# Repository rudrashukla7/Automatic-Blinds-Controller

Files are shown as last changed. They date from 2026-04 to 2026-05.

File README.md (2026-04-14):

# Automatic-Blinds-Controller

A WiFi-enabled automated blinds system using an **ESP32**, **DRV8825 stepper driver**, and a **NEMA 17 stepper motor**.  
The system hosts a built-in web interface that allows real-time control of blinds from any device on the same network.

---

## Features

- Web-based control (no app required)
- Clean, responsive UI hosted directly on ESP32
- Smooth motion using 1/16 microstepping
- Manual open / close controls
- Timed movement (5-second presets)
- Instant stop functionality
- Dual-core multitasking (motor control runs independently)
- Quiet and precise operation

---

## Components Used

- ESP32 Development Board (30-pin NodeMCU)
- NEMA 17 Stepper Motor (12V, 1.5A)
- DRV8825 Stepper Motor Driver
- 12V battery or power supply
- Buck converter (5V for ESP32)
- 220µF capacitor (≥35V recommended)
- Jumper wires
- 3D printed gear (for #10 bead chain)
- Latch switch

---

## Wiring Diagram

- **Battery +** → DRV8825 VMOT → Buck Converter IN+  
- **Battery −** → DRV8825 GND → Buck IN− → Buck OUT− → ESP32 GND  

- **Buck OUT+ (5V)** → ESP32 VIN  

- **ESP32 GPIO26** → DRV8825 STEP  
- **ESP32 GPIO27** → DRV8825 DIR  
- **ESP32 GPIO25** → DRV8825 EN (LOW = enable)  

- **DRV8825 RST → SLP → ESP32 3.3V**  

- **Microstepping Configuration:**  
  - M0 = 3.3V  
  - M1 = 3.3V  
  - M2 = GND  → (1/16 microstepping)

- **Capacitor:** across VMOT and GND (placed close to driver)

- **Motor Wiring:**  
  - A1 = Black  
  - A2 = Green  
  - B1 = Red  
  - B2 = Blue  

> All grounds must be connected together for proper operation.

---

## Web Interface



The ESP32 hosts a web dashboard accessible through its IP address.

### Controls

- **Open / Close** → Full movement  
- **Open 5s / Close 5s** → Timed movement  
- **Stop** → Immediately halts motor  

---

## How It Works

1. ESP32 connects to WiFi using provided credentials  
2. A web server runs on port 80  
3. User accesses the ESP32 IP address in a browser  
4. Button presses send HTTP requests to the ESP32  
5. A motor task is created on Core 0  
6. Stepper motor is driven via STEP/DIR signals  
7. Stop command interrupts motion using a shared flag  

The DRV8825 driver converts STEP and DIR signals into precise motor movement, allowing smooth control with microstepping :contentReference[oaicite:0]{index=0}.

---

## Default Settings

- Microstepping: 1/16  
- Step delay: 750 µs  
- Full movement: ~10 rotations (32000 steps)  
- Timed movement: ~5 seconds (3333 steps)  

---

## 3D Printed Parts

Custom parts are used to interface with the blinds system.

### Files

- `blinds_gear.stl` – engages with #10 bead chain  
- `housing.stl` – enclosure for electronics
- `lid.stl` – close the housing  

### Notes

- Designed for #10 bead chain (4mm beads, 2mm spacing)
- Recommended material: PLA or PETG
- Ensure proper fit before installation

---

## Libraries Used

- WiFi (ESP32 core)
- WebServer (ESP32 core)

Included automatically with the ESP32 Arduino package.

---

## Uploading the Code

1. Open `Automatic Blinds Controller Code.ino` in Arduino IDE  
2. Select **Board → ESP32 Dev Module**  
3. Select the correct **COM Port**  
4. Update WiFi credentials:
   ```cpp
   const char* ssid = "your_wifi";
   const char* password = "your_password";
   ```
5. Click **Upload**

---

## Running the System

1. Power the system with a 12V supply  
2. Open Serial Monitor (115200 baud)  
3. Note the ESP32 IP address  
4. Enter the IP address into a browser  
5. Use the interface to control blinds  

---

## Future Improvements

- Limit switches for position detection  
- Position tracking (percentage open/closed)  
- Mobile app or remote access  
- Smart home integration (Alexa / Google Home)  
- Adjustable speed profiles

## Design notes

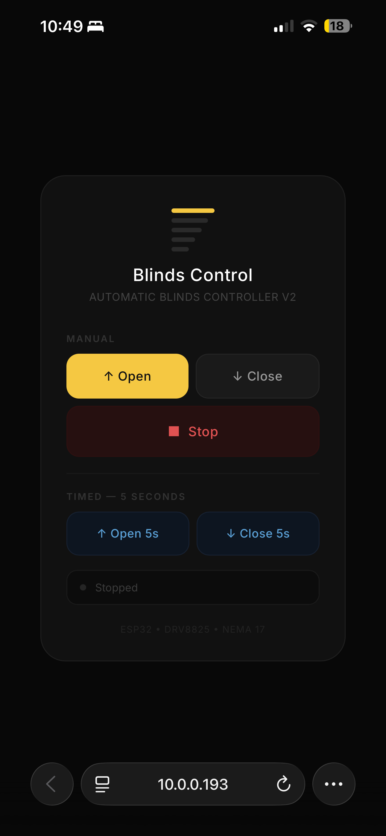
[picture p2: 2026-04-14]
Web Interface.png

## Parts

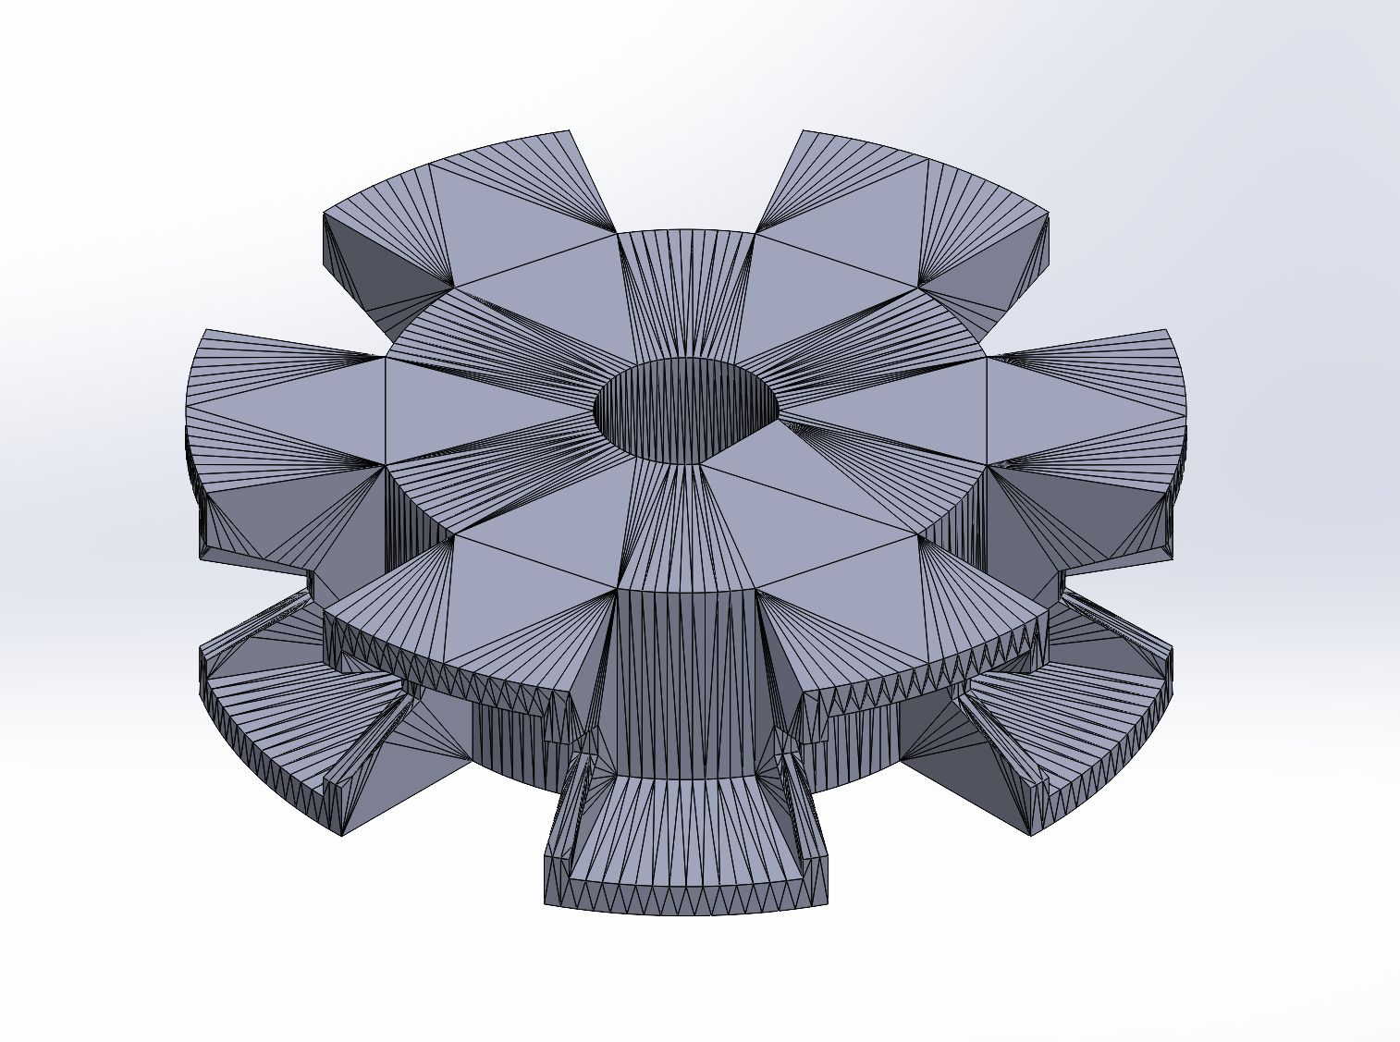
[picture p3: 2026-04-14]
3D Printed Parts/Gear Image.png

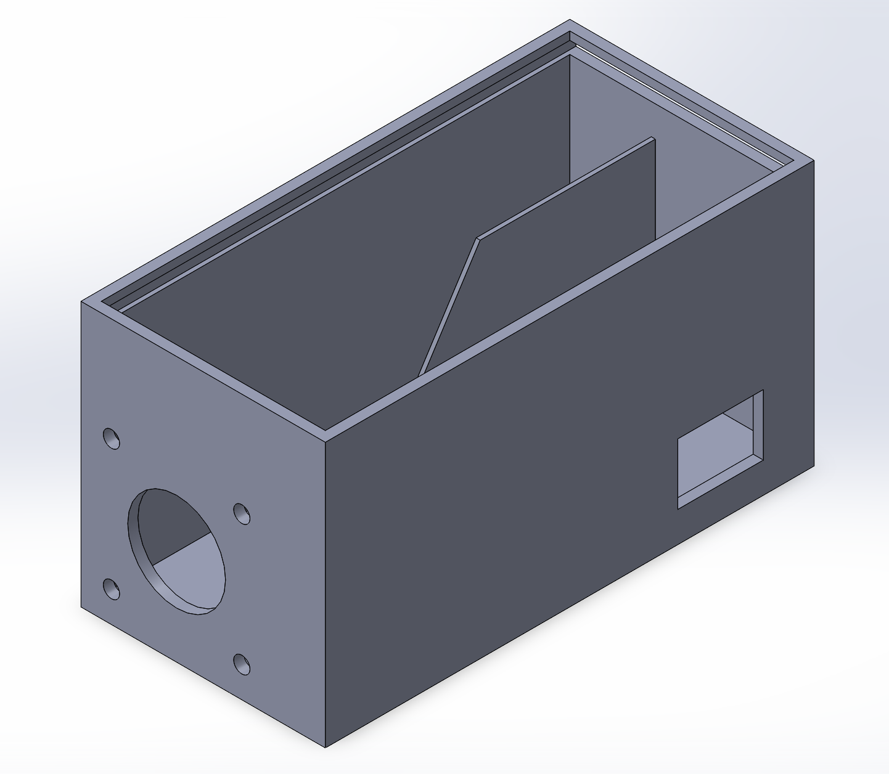
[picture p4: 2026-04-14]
3D Printed Parts/Housing Image.png

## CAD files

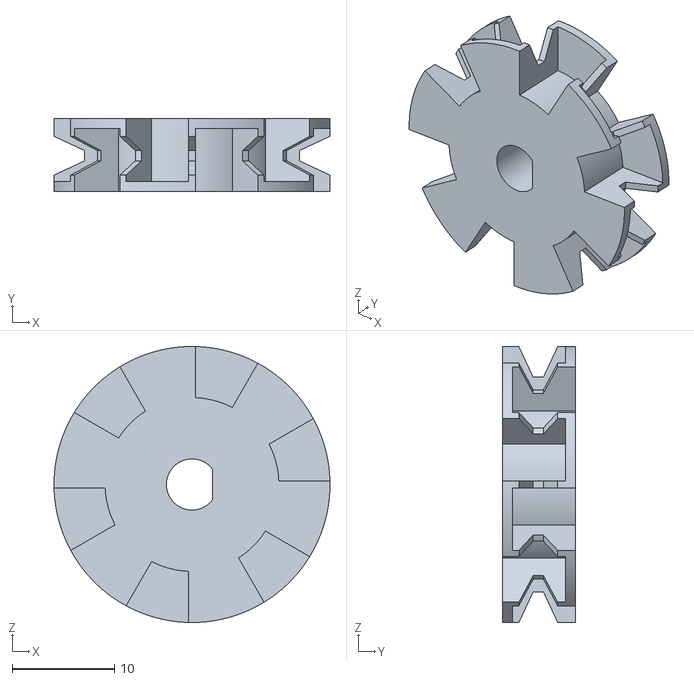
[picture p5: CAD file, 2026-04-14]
STL Files/blinds_gear.STL
27.0 x 7.14 x 27.0

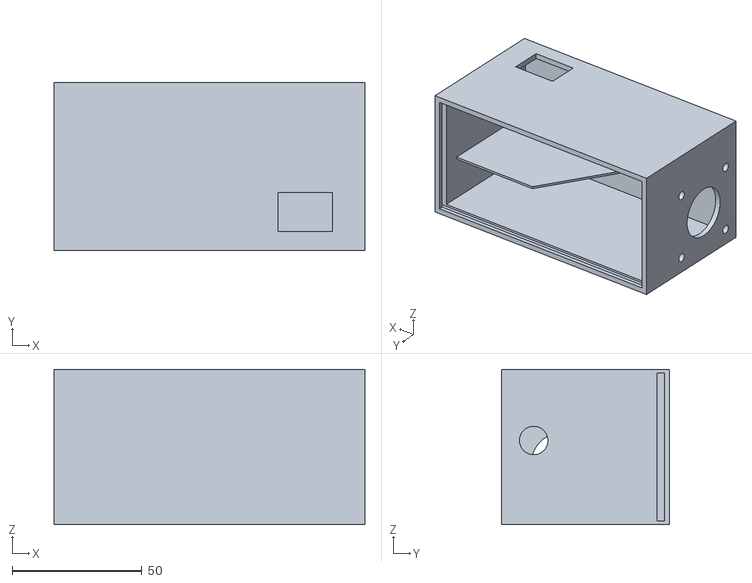
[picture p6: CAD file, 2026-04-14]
STL Files/housing.STL
120.0 x 65.0 x 60.0

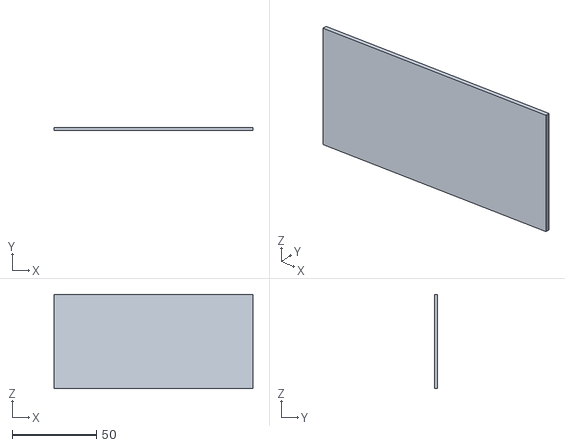
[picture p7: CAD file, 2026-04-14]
STL Files/lid.STL
118.0 x 2.00 x 56.0

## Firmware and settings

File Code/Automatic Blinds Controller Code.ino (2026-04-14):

// Automatic Blinds Controller
// NEMA 17, DRV8825, 1/16 microstepping, ESP32

#include <WiFi.h>
#include <WebServer.h>

// WiFi Credentials
const char* ssid = "your_wifi";
const char* password = "your_password";

// Pin Definitions
#define STEP 26
#define DIR 27
#define EN 25

// 1/16 microstepping
#define STEP_DELAY 750
#define STEPS_PER 32000  // 10 rotations 
#define STEPS_5SEC 3333   // ~5 seconds of movement

WebServer server(80);

// Shared between cores
volatile bool stopFlag = false;
volatile bool motorActive = false;

//Motor Command
struct MotorCommand {
  int  steps;
  bool clockwise;
};

MotorCommand pendingCmd = {0, true};
TaskHandle_t motorTaskHandle = NULL;

// HTML Page 
const char htmlPage[] PROGMEM = R"=====(
<!DOCTYPE html>
<html lang="en">
<head>
  <meta charset="UTF-8">
  <meta name="viewport" content="width=device-width, initial-scale=1.0">
  <title>Blinds</title>
  <link rel="preconnect" href="https://fonts.googleapis.com">
  <link href="https://fonts.googleapis.com/css2?family=Inter:wght@300;400;500;600&display=swap" rel="stylesheet">
  <style>
    * {
      box-sizing: border-box;
      margin: 0;
      padding: 0;
    }

    body {
      font-family: 'Inter', sans-serif;
      background: #080808;
      color: #f0f0f0;
      min-height: 100vh;
      display: flex;
      flex-direction: column;
      align-items: center;
      justify-content: center;
      padding: 24px;
    }

    .card {
      background: #111111;
      border: 1px solid #1f1f1f;
      border-radius: 28px;
      padding: 36px 28px 28px;
      width: 100%;
      max-width: 340px;
    }

    /*  Header  */
    .header {
      text-align: center;
      margin-bottom: 32px;
    }

    .blind-icon {
      width: 48px;
      height: 48px;
      margin: 0 auto 14px;
      display: flex;
      flex-direction: column;
      justify-content: space-between;
    }

    .blind-slat {
      height: 5px;
      border-radius: 3px;
      background: #2a2a2a;
    }

    /* Staggered slats — top one highlighted in yellow */
    .blind-slat:nth-child(1) { background: #f5c842; width: 100%; }
    .blind-slat:nth-child(2) { width: 85%; }
    .blind-slat:nth-child(3) { width: 70%; }
    .blind-slat:nth-child(4) { width: 55%; }
    .blind-slat:nth-child(5) { width: 40%; }

    h1 {
      font-size: 1.2rem;
      font-weight: 500;
      color: #ffffff;
      letter-spacing: 0.02em;
    }

    .subtitle {
      font-size: 0.75rem;
      color: #444;
      margin-top: 5px;
      letter-spacing: 0.03em;
    }

    /*  Section Labels  */
    .section-label {
      font-size: 0.65rem;
      font-weight: 600;
      letter-spacing: 0.14em;
      color: #333;
      text-transform: uppercase;
      margin-bottom: 10px;
    }

    /*  Buttons  */
    .btn-row {
      display: flex;
      gap: 8px;
      margin-bottom: 8px;
    }

    button {
      flex: 1;
      padding: 15px 10px;
      font-size: 0.88rem;
      font-weight: 500;
      font-family: 'Inter', sans-serif;
      border: none;
      border-radius: 14px;
      cursor: pointer;
      transition: opacity 0.12s ease, transform 0.12s ease;
      letter-spacing: 0.02em;
    }

    button:active {
      transform: scale(0.95);
      opacity: 0.85;
    }

    .btn-open {
      background: #f5c842;
      color: #111;
    }

    .btn-open:hover {
      background: #f9d45a;
    }

    .btn-close {
      background: #1a1a1a;
      color: #999;
      border: 1px solid #252525;
    }

    .btn-close:hover {
      background: #1f1f1f;
    }

    /* Distinct red-tinted style to stand out from other buttons */
    .btn-stop {
      width: 100%;
      display: block;
      padding: 16px;
      background: #1e0a09;
      color: #e05252;
      border: 1px solid #2e1010;
      font-size: 0.92rem;
      border-radius: 14px;
      margin-bottom: 8px;
      cursor: pointer;
      font-family: 'Inter', sans-serif;
      font-weight: 500;
      transition: opacity 0.12s ease, transform 0.12s ease;
      letter-spacing: 0.02em;
    }

    .btn-stop:hover {
      background: #261010;
    }

    .btn-stop:active {
      transform: scale(0.95);
      opacity: 0.85;
    }

    .btn-timed {
      background: #0d1520;
      color: #5a9fd4;
      border: 1px solid #162030;
      font-size: 0.82rem;
    }

    .btn-timed:hover {
      background: #111c2a;
    }

    /*  Divider  */
    .divider {
      border: none;
      border-top: 1px solid #191919;
      margin: 18px 0;
    }

    /*  Status Bar  */
    .status-bar {
      background: #0c0c0c;
      border: 1px solid #1a1a1a;
      border-radius: 12px;
      padding: 11px 14px;
      margin-top: 16px;
      display: flex;
      align-items: center;
      gap: 10px;
    }

    /* Dot changes colour based on state: idle / active / error */
    .dot {
      width: 7px;
      height: 7px;
      border-radius: 50%;
      background: #252525;
      flex-shrink: 0;
      transition: background 0.4s ease;
    }

    .dot.active { background: #f5c842; }
    .dot.error { background: #e05252; }

    #status {
      font-size: 0.75rem;
      color: #3a3a3a;
      transition: color 0.3s;
    }

    #status.active { color: #888; }
    #status.error { color: #e05252; }

    /*  Footer  */
    .footer {
      text-align: center;
      margin-top: 20px;
      font-size: 0.65rem;
      color: #222;
      letter-spacing: 0.06em;
    }
  </style>
</head>
<body>
  <div class="card">

    <div class="header">
      <div class="blind-icon">
        <div class="blind-slat"></div>
        <div class="blind-slat"></div>
        <div class="blind-slat"></div>
        <div class="blind-slat"></div>
        <div class="blind-slat"></div>
      </div>
      <h1>Blinds Control</h1>
      <p class="subtitle">AUTOMATIC BLINDS CONTROLLER V2</p>
    </div>

    <p class="section-label">Manual</p>
    <div class="btn-row">
      <button class="btn-open"  onclick="send('/motor/cw','Opening...','active')">&#x2191; Open</button>
      <button class="btn-close" onclick="send('/motor/ccw','Closing...', 'active')">&#x2193; Close</button>
    </div>
    <button class="btn-stop" onclick="send('/motor/stop', 'Stopping...', 'error')">&#x25A0;&nbsp; Stop</button>

    <hr class="divider">

    <p class="section-label">Timed &mdash; 5 seconds</p>
    <div class="btn-row">
      <button class="btn-timed" onclick="send('/motor/cw5','Opening for 5s...', 'active')">&#x2191; Open 5s</button>
      <button class="btn-timed" onclick="send('/motor/ccw5', 'Closing for 5s...', 'active')">&#x2193; Close 5s</button>
    </div>

    <div class="status-bar">
      <div class="dot" id="dot"></div>
      <span id="status">Ready</span>
    </div>

    <p class="footer">ESP32 &bull; DRV8825 &bull; NEMA 17</p>

  </div>

  <script>
    // Sends a request to the ESP32 and updates the status bar with the response
    async function send(path, msg, state) {
      setStatus(msg, state);
      try {
        const res= await fetch(path);
        const txt = await res.text();
        setStatus(txt, '');
      } catch(e) {
        setStatus('Connection error', 'error');
      }
    }

    // Updates status text and dot colour
    function setStatus(msg, state) {
      const el= document.getElementById('status');
      const dot = document.getElementById('dot');
      el.textContent = msg;
      el.className = state || '';
      dot.className = 'dot' + (state ? ' ' + state : '');
    }
  </script>
</body>
</html>
)=====";

// Motor Task Core 0 
void motorTask(void* param) {
  disableCore0WDT(); // prevent watchdog from stopping long moves

  MotorCommand* cmd = (MotorCommand*)param;
  int  steps     = cmd->steps;
  bool clockwise = cmd->clockwise;

  digitalWrite(DIR, clockwise ? HIGH : LOW);
  delay(1); 
  digitalWrite(EN, LOW);

  for (int i = 0; i < steps; i++) {
    if (stopFlag) break; 
    digitalWrite(STEP, HIGH);
    delayMicroseconds(STEP_DELAY);
    digitalWrite(STEP, LOW);
    delayMicroseconds(STEP_DELAY);
  }

  // disable driver 
  digitalWrite(EN, HIGH); 
  motorActive = false;
  motorTaskHandle = NULL;

  // task deletes itself
  vTaskDelete(NULL); 
}

// Start motorTask Core 0
void startMotor(int steps, bool clockwise) {

  //Stops active movement
  if (motorActive) {
    stopFlag = true;

    // Let motor spin
    while (motorActive){
      delay(10); 
    } 
  }

  // Reset values
  stopFlag = false;
  motorActive = true;
  delay(10);

  pendingCmd = {steps, clockwise};

  xTaskCreatePinnedToCore(
    motorTask,       // function
    "motorTask",     // name
    2048,            // stack size
    &pendingCmd,     // argument
    1,               // priority
    &motorTaskHandle,// handle
    0                // core 0
  );
}

// Route Handlers
// Each sends a response immediately so the browser doesn't retry

void handleRoot() {
  server.send_P(200, "text/html", htmlPage); // send from flash, not RAM
}

void handleCW() {
  server.send(200, "text/plain", "Opening");
  startMotor(STEPS_PER, true);
}

void handleCCW() {
  server.send(200, "text/plain", "Closing");
  startMotor(STEPS_PER, false);
}

void handleCW5() {
  server.send(200, "text/plain", "Opening for 5s");
  startMotor(STEPS_5SEC, true);
}

void handleCCW5() {
  server.send(200, "text/plain", "Closing for 5s");
  startMotor(STEPS_5SEC, false);
}

void handleStop() {
  stopFlag = true;
  server.send(200, "text/plain", "Stopped");
  stopFlag = false; // clear flag so next command starts fresh
}

void handleNotFound() {
  server.send(404, "text/plain", "Not found");
}

// Setup
void setup() {
  Serial.begin(115200);

  pinMode(STEP, OUTPUT);
  pinMode(DIR,OUTPUT);
  pinMode(EN,OUTPUT);
  digitalWrite(EN, HIGH);

  Serial.print("Connecting to WiFi");
  WiFi.mode(WIFI_STA); // station mode
  WiFi.begin(ssid, password);
  while (WiFi.status() != WL_CONNECTED) {
    delay(500);
    Serial.print(".");
  }
  Serial.println("\nConnected! IP: " + WiFi.localIP().toString());

  // Register URL routes
  server.on("/", handleRoot);
  server.on("/motor/cw", handleCW);
  server.on("/motor/ccw", handleCCW);
  server.on("/motor/stop", handleStop);
  server.on("/motor/cw5", handleCW5);
  server.on("/motor/ccw5", handleCCW5);
  server.onNotFound(handleNotFound);

  server.begin();
  Serial.println("Web server started.");
}

// Void loop
void loop() {
  server.handleClient();
}

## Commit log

2026-03-16 Stepper Test Code Upload
2026-03-16 Enhance README with project details and instructions
    Added detailed project description, features, components, wiring diagram, and usage instructions.
2026-04-14 Revise README.md for clarity and detail
    Updated features, components, wiring diagram, and usage instructions in README.md.
2026-04-14 Revise README for improved clarity and detail
    Updated README to enhance clarity and detail about features, components, wiring, web interface, and future improvements.
2026-04-14 Added custom 3D Designed parts
    [blinds_gear.STL, housing.STL, lid.STL]
2026-04-14 added stl filed and 3D componentd to README
    Updated the README to clarify features, components, and instructions.
